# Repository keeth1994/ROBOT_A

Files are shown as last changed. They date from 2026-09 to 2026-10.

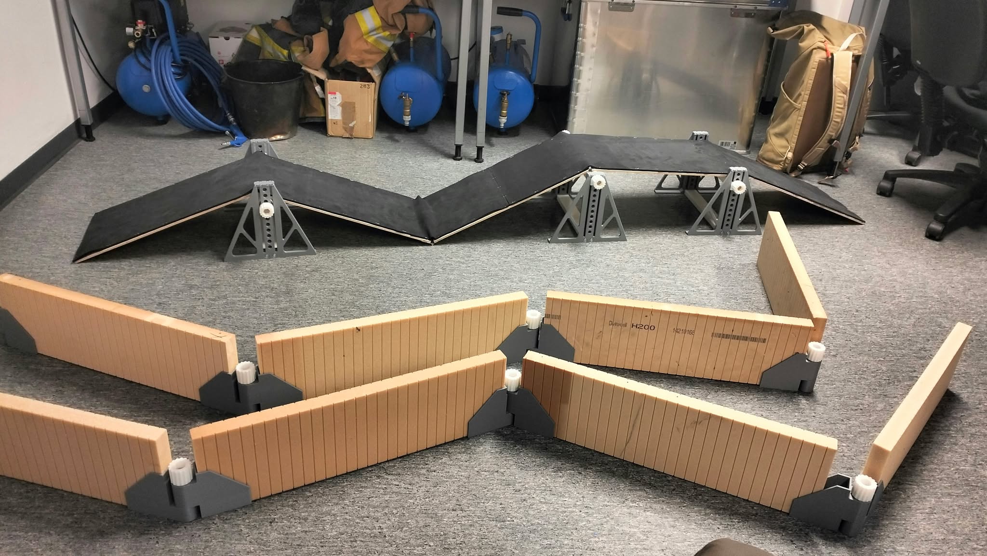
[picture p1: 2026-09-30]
reference/obstacle_course.jpg

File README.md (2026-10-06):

# Robot B9-1

Current Fusion assembly and CAD-derived MuJoCo simulation, using eight original Parallax servos and a physics-driven walking controller.

## Run

From this folder in PowerShell:

```powershell
.\.venv\Scripts\python.exe robot.py walk
.\.venv\Scripts\python.exe robot.py walk --ramp --seconds 100
.\.venv\Scripts\python.exe robot.py walk --test --seconds 15
.\.venv\Scripts\python.exe robot.py check all
```

`start.ps1` and Ctrl+Shift+B in VS Code start the course. Run `robot.py --help` for available commands. No RL training pipeline or trained policy is included.

## Current files

- [Fusion assembly](cad/B9_1/Robot_B9_1.f3d)
- [STEP assembly](cad/B9_1/Robot_B9_1.step)
- [CAD workflow](cad/README.md)
- [Simulation assumptions and results](docs/DESIGN_B91_SIM.md)
- [Machine-readable current design](cad/current_design.json)

| Folder | Contents |
|---|---|
| `robot_b91/` | Model builder, walking controller, geometry and terrain helpers |
| `cad/` | Current assembly, source yaw and Fusion exporter |
| `reference/` | Current CAD export, mass, kinematics, gait and terrain settings |
| `models/` | MuJoCo models and visual meshes |
| `tests/` | Model and entry-point checks |
| `results/` | Current standing, walking and course reports plus preview |

## Setup and rebuild

Use Python 3.12 and install `requirements.txt` into `.venv`. The lock file records pinned dependencies.

After CAD edits, export the saved assembly using `cad/ExportB91` inside Fusion, then run `robot.py build`. This regenerates the simulation from the CAD export. Edit `reference/b91_course_settings.json` to change terrain, then rebuild.

The provisional mass is 1.21 kg. The initial flat test moved 0.505 m in 15 seconds without falling. The 100-second course test drifted and fell; successful course traversal is not established. Physical mass, friction, tolerances and strength still need verification.

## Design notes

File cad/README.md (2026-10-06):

# B9-1 CAD

Open [Robot_B9_1.f3d](B9_1/Robot_B9_1.f3d) in Fusion, or use the [STEP assembly](B9_1/Robot_B9_1.step). The saved assembly is the starting point for edits.

`B9_1/User_yaw_backup.f3d` preserves the source of the current edited fork. Component names inside the assembly retain their original identifiers for traceability.

For simulation export, register `ExportB91` in Fusion Scripts and Add-Ins. It reads the saved archive and writes `reference/b91_cad_meshes.json.gz`. Then run `robot.py build` to regenerate MuJoCo assets. The exporter does not capture unsaved active-tab changes.

See [mechanical notes](B9_1/README.md) and [simulation notes](../docs/DESIGN_B91_SIM.md).

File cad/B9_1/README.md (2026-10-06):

# B9-1 assembly

`Robot_B9_1.f3d` and `Robot_B9_1.step` contain the full assembly. `assembly.png` shows the model. The current edited fork source is retained in `User_yaw_backup.f3d`.

The chassis underside is extended 4 mm to the bearing-housing base plane, retaining openings and bearing seats. Added CAD volume is approximately 48.9 cm3.

`check_report.json` records 784 neutral and sampled pitch clearance checks with no intersections above 0.1 mm3 in the checked pairs. Pitch was sampled from -45 to +45 degrees. Full yaw clearance, physical fit, access and strength remain unverified.

The assembly is transferred to MuJoCo. See [simulation notes](../../docs/DESIGN_B91_SIM.md).

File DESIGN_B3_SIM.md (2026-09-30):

# B3 simulation: narrow feet and supplied sensors

## Model

Native Fusion and STEP exports, CAD-derived visual meshes, approximate inertias and contact shapes are rebuilt from the same B3 geometry. Runner length is 42 mm, flat sole 8 mm, inward tread radius 12 mm, outward tread radius 22 mm, PLA thickness 3 mm and radial section 5 mm. Pitch axle is 60 mm above the neutral sole. Inward reach is deliberately shorter (18 mm versus 24 mm outward).

Estimated total mass: 1.1094 kg. Solid PLA: 284.2 g. Sensor mass additions and the retained electronics/fastener allowances are itemized in `reference/robot_b3_manifest.json`. These are not measured or sliced masses.

Original Parallax 900-00005 servos remain: pitch stall limit 0.26834 Nm, yaw output 0.15206 Nm after 1.5 speed-increasing gears and assumed 85% efficiency. Torque decreases with motoring speed; no thermal, battery-sag or backlash model. Pitch and yaw are limited to +/-45 degrees. Full requested 270-degree yaw is not clearance-certified.

## Course and controller

The photo-inspired ramp has a 300 mm width and five 600 mm horizontal sections. Its provisional height profile is 0 -> 160 -> 0 -> 200 -> 200 -> 0 mm: first climb, first descent into a valley, second climb, raised flat platform, final descent. Thin 6 mm rigid panels have black surfaces, exposed wood-coloured edges and simplified supports. The first slopes are about +/-14.9 degrees and the second climb/descent +/-18.4 degrees. The checkerboard floor remains for visual tracking. Dimensions are assumptions pending measurements; flex and grip are not calibrated.

An independently positioned open zigzag corridor has a provisional 400 mm clear width, 180 mm wall height and 12 mm wall thickness. The settings file exposes both obstacles' positions, rotations and dimensions. There is no ceiling because the photograph shows open walls. The existing controller is unchanged and cannot be assumed to navigate from the ramp into this corridor.

The programmed gait acts through torque/speed-limited motors, without teleportation, base forces or terrain-specific choreography. Ideal simulated heading and lateral feedback remain. After reducing the feet, yaw sweep direction was changed to +0.45 rad; no other gait gains were changed. An earlier unchanged-gait comparison is retained separately and is not the current run.

## Previous-geometry tests (not rerun)

The programmed-gait tests below have not been rerun for the short-sole/rounded-toe revision; new RL experiments on that geometry are documented in `RL_B3.md` and `RL_CURRICULUM.md`. On the preceding foot geometry, the 100 s run advanced 0.499 m, contacted first_climb, floor, and did not complete the ramp. Detected fall: False; warnings: 0; maximum tilt 16.06 degrees. Those previous-geometry results remain in `results/b3_course_test.json` and the replay. The pass criterion requires contact with all five ramp surfaces, clearance of the ramp exit, no fall, no non-foot contact and no ramp-width violation. It assesses the ramp only, not successful corridor navigation. Geometry and sensor validation do not prove traversal capability.

## Sensors

Three Sharp GP2Y0A41SK0F rays provide left, right and downward-forward range observations. Outside 4-30 cm is unknown. MC6470 accelerometer and magnetometer channels are present, with no invented gyro. The TimerCamera-X is represented by a forward RGB camera. `b3_sensors.py` logs observations and captures a camera view. `test_b3_sensors.py` checks wall distances, ground-ray orientation, invalid ranges and channel presence. These tests passed on the previous foot geometry; analogue noise, surface reflectivity, magnetic interference and perception software remain unmodelled. The gait does not yet use these readings. See `SENSORS_B3.md`.

## CAD checks

The audit has 59 recorded overlap cases; inspect `cad/B3_clearance_audit.json` for scope and locations. Own pitch is sampled at 5-degree intervals, FL neutral-pitch yaw at 15 degrees, sensor-vs-leg poses at yaw/pitch -45/0/+45 for all four legs, and stationary sensor packaging is checked. Combined continuous poses, neighbouring moving legs, wiring and strength are not certified. Sensor brackets and other small mounting details contribute mass but are not fully represented by MuJoCo contact geometry.

## Files

`cad/` holds native exports and previews. `models/` holds flat and course XML plus visual meshes. `reference/` holds geometry, sensor and gait configuration. `results/` holds previous-geometry metrics, replay, sensor log and camera view.

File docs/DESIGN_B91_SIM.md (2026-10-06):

# B9-1 MuJoCo transfer

`robot.py walk` and `robot.py build` now use B9-1. The default VS Code course task and `start.ps1` also use B9-1. Use `walk --test` for a saved report. No trained policy or RL training pipeline is included.

```powershell
.\.venv\Scripts\python.exe robot.py walk
.\.venv\Scripts\python.exe robot.py walk --ramp --seconds 100
.\.venv\Scripts\python.exe robot.py walk --test --seconds 15
.\.venv\Scripts\python.exe robot.py check b91
```

## Source and rebuild

Saved source: `cad/B9_1/Robot_B9_1.f3d`. The Fusion exporter `cad/export_b91_sim.py` loads this archive and exports 97 bodies in assembly coordinates to `reference/b91_cad_meshes.json.gz`, including source SHA-256. To run the exporter, register `cad/ExportB91` in Fusion Scripts and Add-Ins. It does not edit the CAD source. Save any new design edits into the source archive before exporting.

`robot.py build` verifies the archive hash, regenerates `models/robot_b91.xml`, `models/robot_b91_course.xml`, their meshes and the mass manifest. Course settings are in `reference/b91_course_settings.json`. B9-1 course metadata is saved separately.

## Mechanical model

- Neutral size: approximately 272 x 272 x 132 mm.
- Yaw axes at (+/-52, +/-52) mm; pitch axes at local (55, 0, 35) mm.
- Pitch motors and rockers move together; the original pitch crosses remain on the yaw forks.
- Eight torque-controlled actuators. Original servo stall limit 0.26834 Nm; yaw output 0.15206 Nm with assumed 1.5 speed ratio and 85% gear efficiency. Speed reduces available motoring torque using the inherited servo model.
- Pitch and yaw are limited to +/-45 degrees pending broader collision validation. Driver gears follow a joint equality constraint.
- CAD visuals, plus 639 segmented convex collision hulls. Collision surfaces use 0.5 mm vertex clustering; small holes, fasteners and bearing internals are omitted. Concave openings are approximated, not exact contact geometry.
- Provisional total mass 1.20999 kg. `reference/b91_mass.json` defines component allowances and material densities. PLA uses full solid CAD volume; actual manufactured mass can differ. Inertias use per-part bounding boxes and CAD centres of mass.
- Three ideal IR rays, a camera and acceleration sensor at CAD-derived package positions. These are not calibrated electrical sensor models; exact IMU capabilities remain to be confirmed.
- Rigid terrain, assumed friction 0.8, no backlash, thermal limits or flexible parts. No imposed base movement or forced course path.

## Initial checks and results

`tests/test_b91.py` verifies source provenance, body count, mass, pitch-axis positions, moving-link assignments, stable standing, foot-only floor contacts, joint motion and torque limits. Both flat and course XML load successfully.

The programmed gait moved 0.505 m forward with 0.0155 m lateral drift in a 15 s flat test (including 2 s settling), without falling or physics warnings. See `results/b91_walk.json`.

In a 100 s course test it moved 0.873 m forward, drifted 0.209 m sideways and fell (maximum tilt 54.9 degrees). There were no physics warnings. See `results/b91_ramp.json`. This is a failed traversal, not a successful demonstration of the obstacle course.

No learned policy is included or validated for this model.

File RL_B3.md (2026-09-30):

# B3 reinforcement learning on flat ground

This is a separate PPO controller that learns eight absolute yaw/pitch targets. It does not call the programmed gait, prescribe a foot trajectory, teleport the body, or apply external forces. MuJoCo contacts and the original Parallax torque/speed limits produce movement. The existing course controller remains available separately.

## Run

From the repository terminal:

```powershell
.\.venv\Scripts\python.exe -m pip install -r requirements-rl.txt
.\.venv\Scripts\python.exe train_b3_rl.py --strict --steps 262144 --envs 8 --minutes 10
.\.venv\Scripts\python.exe watch_b3_rl.py
```

VS Code: **Terminal > Run Task > B3 RL - train straight line** or **B3 RL - watch learned policy**. The watch command repeats a deterministic 10-second evaluation. The default build task still opens the programmed obstacle-course gait, not RL.

Continue from a saved policy into a new output directory:

```powershell
.\.venv\Scripts\python.exe train_b3_rl.py --resume results/rl_flat/latest.zip --out results/rl_flat_continued --steps 1000000 --minutes 20
.\.venv\Scripts\python.exe watch_b3_rl.py --model results/rl_flat_continued/best.zip
```

`--steps` is the number of additional policy transitions across all environments; each transition represents 20 ms, using ten 2 ms physics steps. The time cap applies during learning; startup and evaluation add time. Checkpoints are local. A policy must be retrained/revalidated when the robot geometry, control mapping or observation definition changes.

## Task and measurement

Each episode starts on the checkerboard floor, settles for 0.3 s, then lasts up to 10 s. Initial joint angles have small seeded perturbations. PPO receives ideal simulator joint angles/velocities, base velocity, angular velocity, orientation, lateral position, height, and its previous action. These are privileged simulator observations; the supplied servo/sensor package does not directly provide all of them. This experiment is not yet a deployable hardware controller.

Reward favours forward velocity and penalizes lateral motion/displacement, heading error, tilt, power, command changes and non-foot floor contact. Episodes terminate for falls, excessive drift/heading, or numerical warnings. Success is at least 0.30 m forward in 10 s, maximum lateral error 0.04 m, maximum heading error 15 degrees, and no fall, non-foot contact or warnings. Distance alone is not success.

The policy outputs joint positions within +/-45 degrees; a PD servo controller uses the same torque-speed envelope as the existing gait. Pitch stall limit is approximately 0.2683 Nm and geared yaw approximately 0.1521 Nm. No motor upgrade. Mass, friction, actuator and inertia approximations are inherited from the current model. No curriculum, gait imitation, phase clock, obstacle navigation or domain randomization is included in this first experiment.

PPO implementation: [Stable Baselines3](https://stable-baselines3.readthedocs.io/en/master/modules/ppo.html), with a [custom Gymnasium environment](https://stable-baselines3.readthedocs.io/en/master/guide/custom_env.html).

## Outputs and checks

`results/rl_flat/` contains standing and untrained baselines, `progress.csv`, periodic `learning_curve.json`, `best.zip`, `latest.zip`, and final `summary.json` with model hash and revision. Best checkpoint means highest evaluation reward, not necessarily successful walking. Check actual success and distance in the summary. Training environments use different seeds; checkpoint evaluation uses seeds 1000-1001 and final reporting 1000-1004. One training seed is a preliminary experiment, not proof of robust learning.

```powershell
.\.venv\Scripts\python.exe test_b3_rl.py
.\.venv\Scripts\python.exe watch_b3_rl.py --record results/rl_flat/replay.mp4
```

The tests check the Gym API, reproducible resets, full-CAD/headless trajectory parity, motor torque caps and absence of external forces. Training removes only non-colliding CAD visual meshes; contact geometry, body masses and inertia remain intact.

## Initial experiment results

See [measured training and evaluation results](results/RL_REPORT.md). The default viewer uses the selected policy in `reference/b3_rl_policy.json`. The first experiment learned forward movement quickly, but passes strict straight-line criteria on only 2/10 new seeds.

`--strict` increases the lateral-displacement penalty from 4 to 15 and the heading penalty from 0.3 to 1.5. Reward weights are recorded in the run summary. Use `evaluate_b3_rl.py --model PATH --episodes 10 --out REPORT.json` for new-seed evaluation; add `--fine` for 1 ms physics.

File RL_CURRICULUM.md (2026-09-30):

# B3 straight-line and gentle-ramp curriculum

These lessons retain the current robot, original motor torque/speed limits, 20 ms policy interval and learned joint-target action space. They use ideal simulator feedback, with no programmed gait, imposed body motion or physical guide rails. No new terrain sensors are invented: the policy reacts using the same body/joint observations as the flat-ground experiment.

Stage 1 is a 10 s flat-ground trial: at least 0.5 m forward, maximum lateral displacement 3 cm, maximum heading error 10 degrees, no fall, non-foot ground contact or warnings. Speed reward saturates at 0.08 m/s, and alignment reduces the reward for faster diagonal motion. Drifting beyond 10 cm or turning beyond 40 degrees ends training episodes.

Stage 2 uses separate 3-degree and 5-degree lessons: 30 cm flat approach, 40 cm ascent, 20 cm level top, 40 cm descent. Ramp width is 30 cm. Heights are approximately 21 mm and 35 mm. The panels are rigid, with the same assumed friction as the existing simulation. Completion requires contact with ascent, top and descent and the body clearing x=1.45 m within 25 s. The same 3 cm/10 degree limits apply. Stepping off the side is a failure. A standing policy cannot pass.

Checkpoint selection prioritizes the success rate on three development seeds, then physical completion, then reward. Twenty separate seeds (4000-4019) assess each selected checkpoint. A stage gate requires 90% success. These seeds vary initial joint angles slightly; they are not a broad hardware/domain-randomization study. Results on gently sloping ramps do not establish capability on the full course.

## Commands

```powershell
.\.venv\Scripts\python.exe train_b3_curriculum.py --resume results/rl_flat_straight/best.zip --out results/curriculum_flat --steps 393216
.\.venv\Scripts\python.exe train_b3_curriculum.py --slope 3 --resume results/curriculum_flat/best.zip --out results/curriculum_3deg --steps 262144
.\.venv\Scripts\python.exe train_b3_curriculum.py --slope 5 --resume results/curriculum_3deg/best.zip --out results/curriculum_5deg --steps 262144
.\.venv\Scripts\python.exe watch_b3_rl.py --curriculum --slope 3 --model results/curriculum_3deg/best.zip
.\.venv\Scripts\python.exe watch_b3_rl.py --curriculum --slope 5 --model results/curriculum_5deg/best.zip
```

Each run saves its initial evaluation, learning curve, best and latest checkpoints, and a summary with validation metrics and model/environment hashes. Continuing from a checkpoint adds `--steps` transitions; it does not reset the learned policy. `--minutes` caps the training portion, with evaluation time additional. Keep each experiment in a distinct output folder.

Checks: `test_b3_curriculum.py` verifies physical ramp heights/width, headless/full-CAD parity, contact accounting and rejection of a stationary policy. `test_b3_rl.py` checks original environment compatibility and actuator limits.

## Observation scaling and continued practice

The refined runs scale small velocity, tilt and lateral-position inputs before the network. The first layer is adjusted when converting an old policy, preserving its initial action mapping. Checkpoint metadata records this convention, and the viewer detects it automatically. `--normalized` enables conversion; later resumes inherit it. `--exploration-std 0.2` or `0.15` reduces exploration during fine-tuning.

Slope runs use two flat and six sloped training environments. After training, the selected ramp policy is also checked on twenty flat-ground seeds (5000-5019) for regression. Existing experiment directories cannot be overwritten by the curriculum trainer.

VS Code offers separate viewing tasks for the refined flat policy and each gentle ramp. These do not replace the original full obstacle-course task.

## Current measured results

See [final fresh-seed report](results/CURRICULUM_REPORT.md). Flat: 20/20 clean passes. 3 degrees: 17/20 physical completions, 6/20 clean passes. 5 degrees: 3/20 physical completions, 1/20 clean pass. These are separate selected checkpoints, not one policy verified for every terrain. Selected files are listed in `reference/b3_curriculum_policies.json`; the default viewer opens the selected flat policy.

The commands above reproduce the original experiment sequence; choose unused output directories when rerunning them. To continue the 5-degree lesson:

```powershell
.\.venv\Scripts\python.exe train_b3_curriculum.py --slope 5 --resume results/curriculum_selected/5deg/policy.zip --out results/curriculum_5deg_next --steps 1000000 --minutes 15
```

For a fresh evaluation, use `--evaluate-only --evaluation-seed 9000` with a new output directory. Viewer `--seed` selects the reset seed.

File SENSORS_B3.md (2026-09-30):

# Supplied project sensors on B3

Selection is based on page 9 (Project components) of `Final project introduction 2026.pdf`. Sensor quantities are a proposed layout; the document does not state available quantities.

| Part | Quantity | Location / purpose |
|---|---:|---|
| Sharp GP2Y0A41SK0F, RS 666-6568 | 3 | One left, one right, one front looking down 30 degrees. Wall clearance and ground profile. |
| MIKROE-4228 / MC6470, RS 249-4068 | 1 | Rigid rear deck cradle. Acceleration and magnetic field. **No gyroscope.** |
| M5Stack TimerCamera-X U082-X, RS 230-5140 | 1 | Forward-facing camera in open deck cradle. RGB observation; no depth output. |

The suggested VL53L5CX, VL53L1X and BMI270 are not in the project list and are not fitted. The listed Ohmite FSR02CE is a 622.3 mm strip, so it is excluded instead of being misrepresented as a small foot pad. No servo position encoders are added.

## Geometry and mass

Sharp packages use the manufacturer's 29.5 x 13 x 13.5 mm envelope and 3.6 g mass. The camera uses 48 x 24 x 15 mm and 14 g. The MC6470 board footprint is 28.6 x 25.4 mm; a 10 mm installed-height envelope and the manufacturer's listed 17 g weight are conservative provisional allowances, to be checked physically. The old 3 g generic IMU reservation is replaced. These are package envelopes, not exact connector/optical-window models.

Open PLA cradles use adhesive pads/cable-tie slots. Body clearance and connector access need physical checks before printing. Sensor cases have dedicated simulation mass and collision boxes. Small cradle collision details remain omitted from MuJoCo, but are included in CAD checks and mass. The 90 g controller/electronics and 80 g miscellaneous allowances remain separate; neither is a finalized bill of materials.

## Simulation interface

`b3_sensors.py` exposes three range readings, 3-axis specific acceleration and magnetic field, plus a `project_camera` RGB view. Run:

```powershell
.\.venv\Scripts\python.exe test_b3_sensors.py
.\.venv\Scripts\python.exe b3_sensors.py --ramp --seconds 3
```

Outputs are `results/b3_sensor_test.json`, `results/b3_sensor_samples.json` and `results/b3_camera_view.png`. Range observations outside 0.04-0.30 m are marked unknown. A missing return is not a proven drop-off. The rays are ideal point samples, not models of Sharp analogue response, beam footprint, dark-rubber reflectance or electrical noise. Magnetometer motor interference is not simulated. Camera FOV uses the published 66.5-degree diagonal angle with an assumed 4:3 image.

The locomotion controller still uses ideal simulated heading/lateral position. Adding sensors does not implement autonomous perception or navigation, and the new sensor data do not secretly replace that feedback. Ground readings change with robot tilt; the listed accelerometer/magnetometer cannot provide gyro rates.

## Wiring notes

Sharp sensors need a regulated 4.5-5.5 V supply, local bypass capacitors and calibrated analogue inputs. Verify ADC voltage protection/dividers for the selected ESP32. The Click board uses 3.3 V I2C. Camera power/communications follow the TimerCamera-X documentation. Measure the installed modules, cable bend space and printed fit before manufacturing.

## Sources

- Project component links: https://no.rs-online.com/web/p/reflective-optical-sensors/6666568 ; https://no.rs-online.com/web/p/sensor-development-tools/2494068 ; https://no.rs-online.com/web/p/development-tool-accessories/2305140
- Sharp datasheet: https://global.sharp/products/device/lineup/data/pdf/datasheet/gp2y0a41sk_e.pdf
- MC6470 board: https://www.mikroe.com/6dof-imu-13-click
- Camera: https://docs.m5stack.com/en/unit/timercam_x
- Ohmite force sensor: https://docs.rs-online.com/8bfb/A700000007054155.pdf

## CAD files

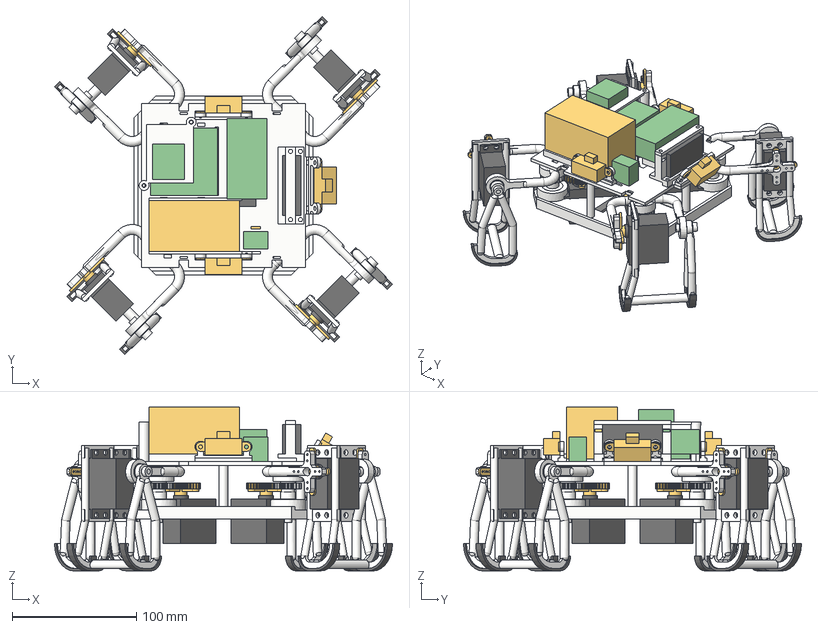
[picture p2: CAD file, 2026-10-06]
cad/B9_1/Robot_B9_1.step
272.3 x 272.3 x 132.0 mm

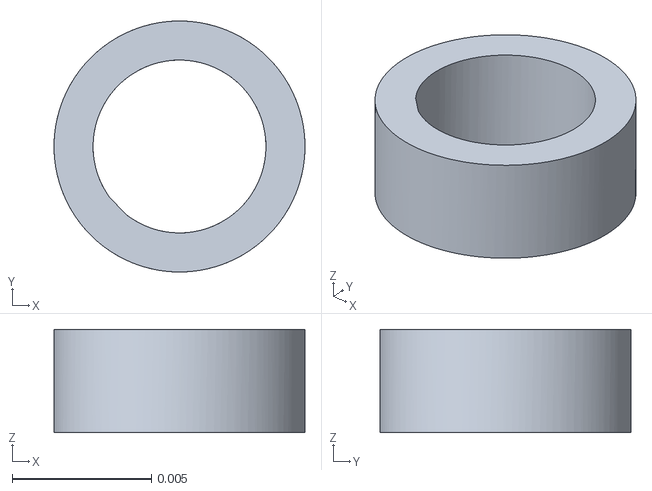
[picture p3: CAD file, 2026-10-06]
models/robot_meshes_b91/cad_72.obj
0.009 x 0.009 x 0.0037

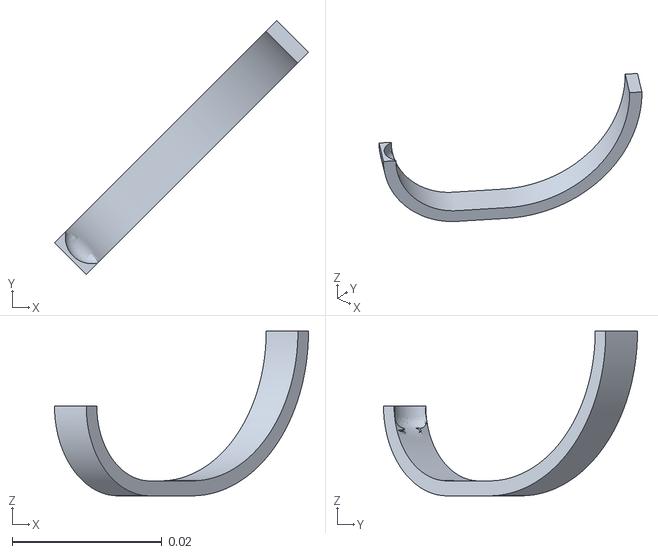
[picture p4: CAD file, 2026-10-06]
models/robot_meshes_b91/cad_9.obj
0.0339 x 0.0339 x 0.022

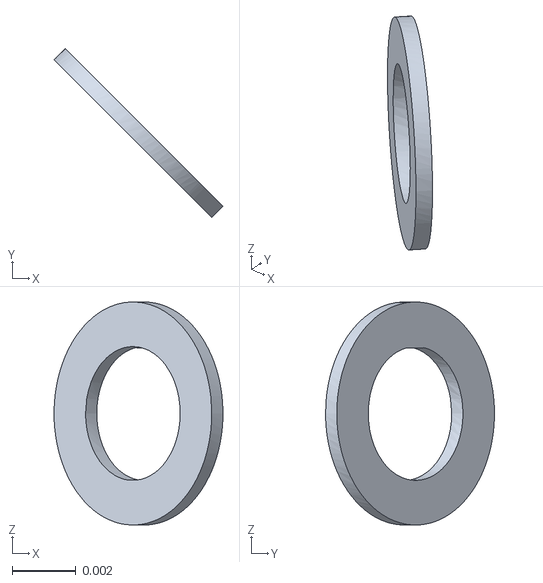
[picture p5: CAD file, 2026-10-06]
models/robot_meshes_b91/cad_70.obj
0.0053 x 0.0053 x 0.007

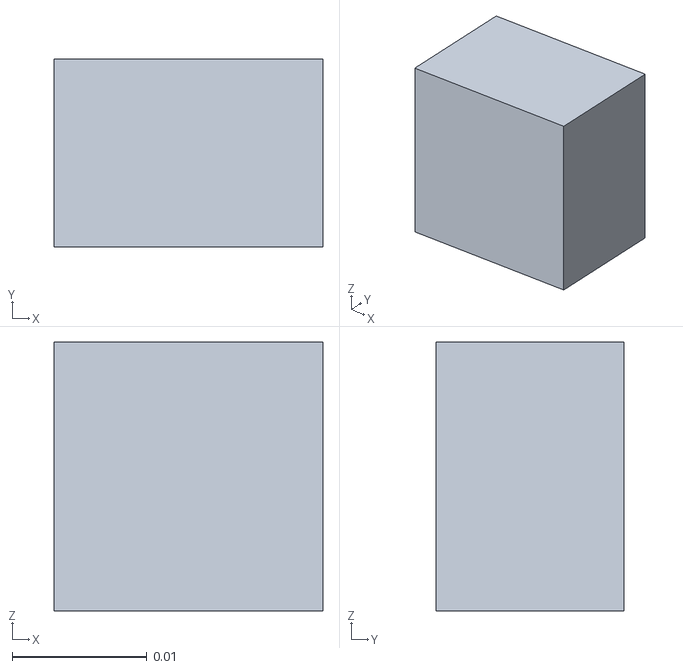
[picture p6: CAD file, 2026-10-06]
models/robot_meshes_b91/cad_96.obj
0.02 x 0.014 x 0.02

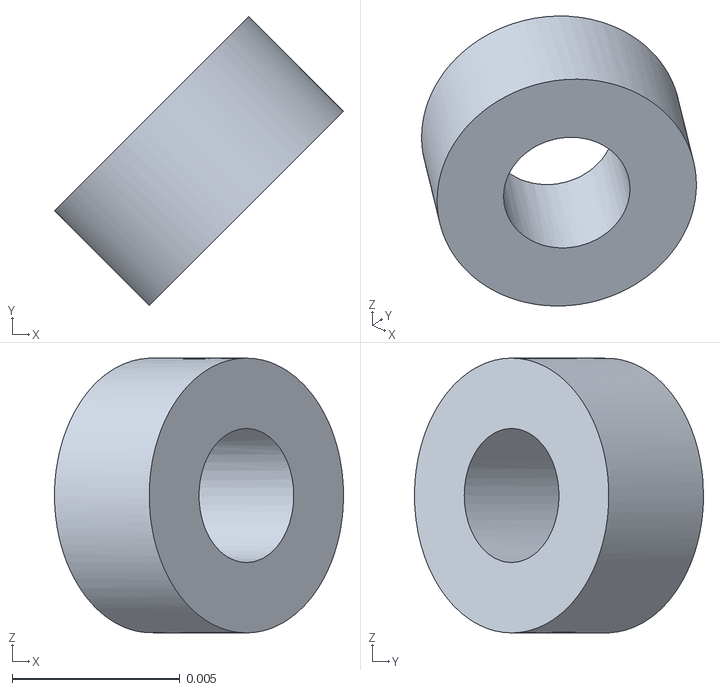
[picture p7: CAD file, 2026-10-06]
models/robot_meshes_b91/cad_53.obj
0.00863 x 0.00863 x 0.0082

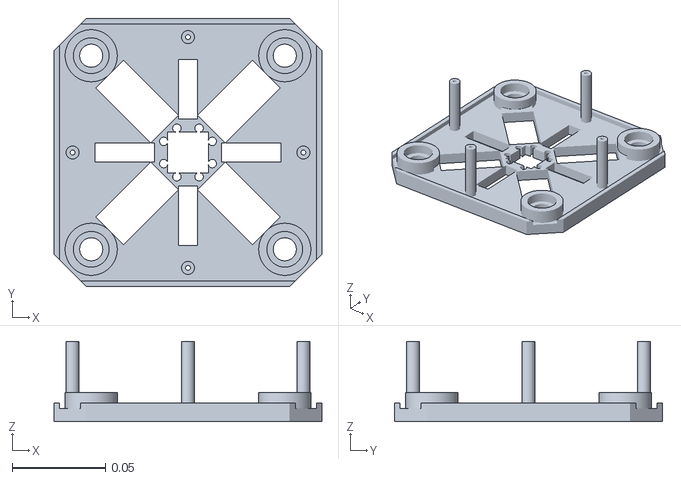
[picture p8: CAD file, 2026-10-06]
models/robot_meshes_b91/cad_0.obj
0.144 x 0.144 x 0.043

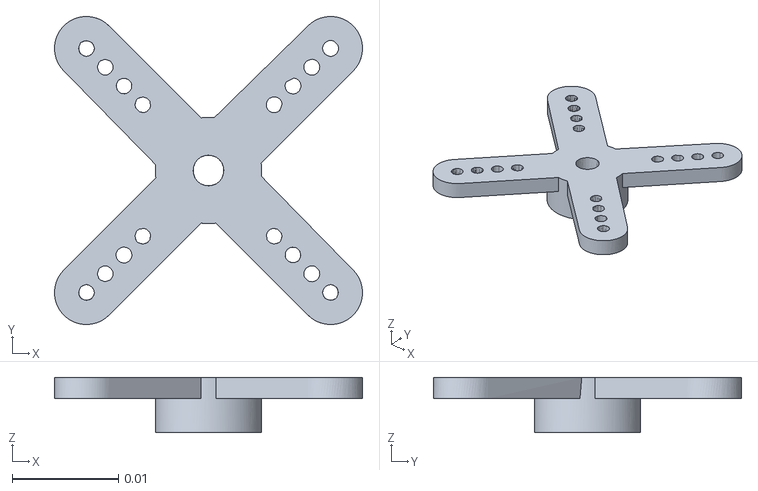
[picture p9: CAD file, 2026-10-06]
models/robot_meshes_b91/cad_66.obj
0.029 x 0.029 x 0.0052

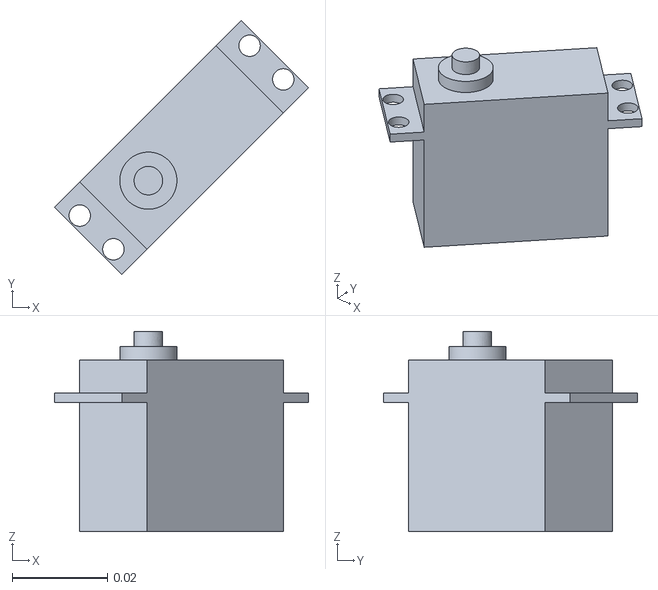
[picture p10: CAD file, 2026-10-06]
models/robot_meshes_b91/cad_26.obj
0.0534 x 0.0534 x 0.0421

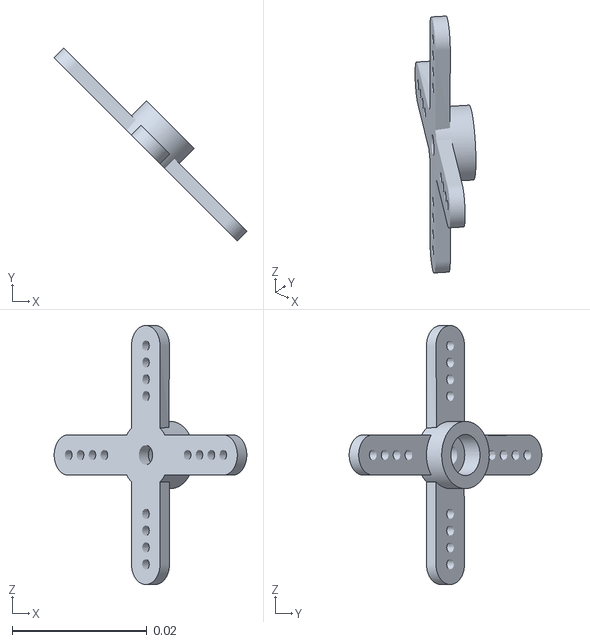
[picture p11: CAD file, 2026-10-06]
models/robot_meshes_b91/cad_22.obj
0.0286 x 0.0286 x 0.0385

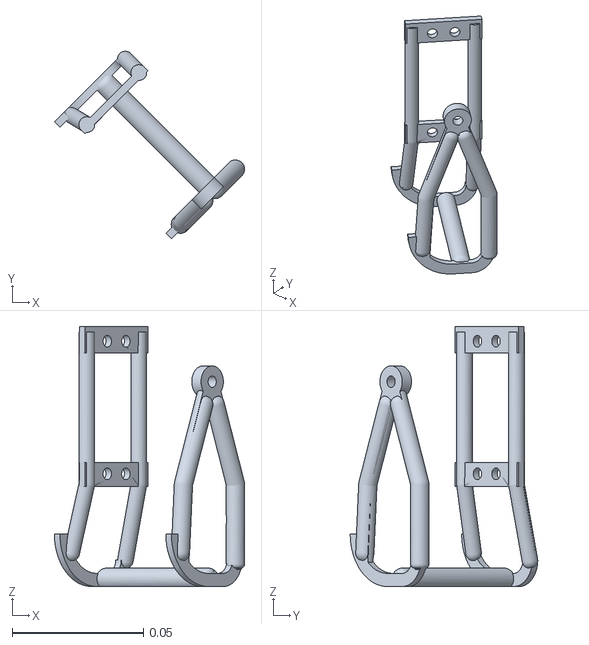
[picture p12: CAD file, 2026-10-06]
models/robot_meshes_b91/cad_31.obj
0.0724 x 0.0714 x 0.099

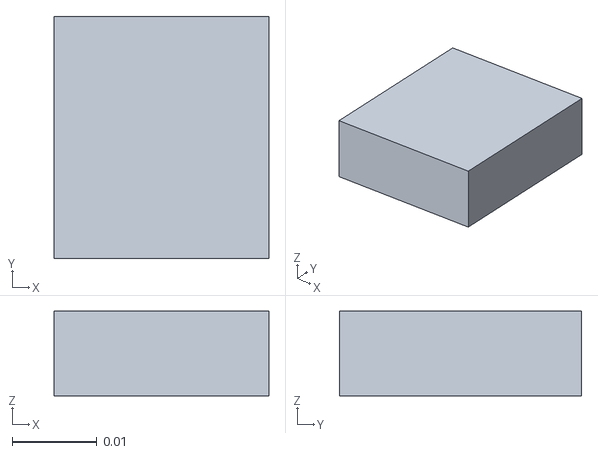
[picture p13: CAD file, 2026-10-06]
models/robot_meshes_b91/cad_95.obj
0.0254 x 0.0286 x 0.01

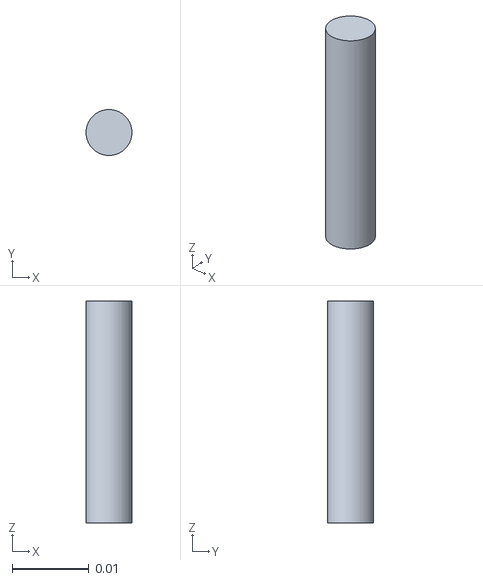
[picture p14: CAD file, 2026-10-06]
models/robot_meshes_b91/cad_73.obj
0.006 x 0.006 x 0.029

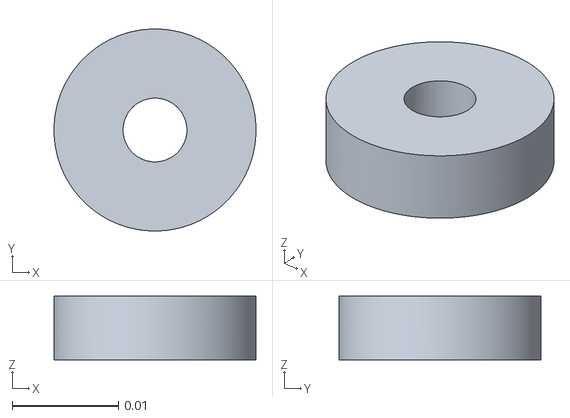
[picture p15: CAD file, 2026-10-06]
models/robot_meshes_b91/cad_68.obj
0.019 x 0.019 x 0.006

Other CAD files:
models/robot_meshes_b91/cad_10.obj
models/robot_meshes_b91/cad_60.obj
models/robot_meshes_b91/cad_79.obj
models/robot_meshes_b91/cad_81.obj
cad/B9_1/Robot_B9_1.f3d
cad/B9_1/User_yaw_backup.f3d
models/robot_meshes_b91/cad_1.obj
models/robot_meshes_b91/cad_11.obj
models/robot_meshes_b91/cad_12.obj
models/robot_meshes_b91/cad_13.obj
models/robot_meshes_b91/cad_14.obj
models/robot_meshes_b91/cad_15.obj
models/robot_meshes_b91/cad_16.obj
models/robot_meshes_b91/cad_17.obj
models/robot_meshes_b91/cad_18.obj
models/robot_meshes_b91/cad_19.obj
models/robot_meshes_b91/cad_2.obj
models/robot_meshes_b91/cad_20.obj
models/robot_meshes_b91/cad_21.obj
models/robot_meshes_b91/cad_23.obj
models/robot_meshes_b91/cad_24.obj
models/robot_meshes_b91/cad_25.obj
models/robot_meshes_b91/cad_27.obj
models/robot_meshes_b91/cad_28.obj
models/robot_meshes_b91/cad_29.obj
models/robot_meshes_b91/cad_3.obj
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

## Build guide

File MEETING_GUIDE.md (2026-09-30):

# Group meeting demos

Double-click MEETING_DEMOS.cmd in the repository and select 1, 2, or 3.
Close the MuJoCo window to exit. Live episodes repeat automatically.
Alternatively, VS Code: Terminal > Run Task > Meeting demo - normal / rl-flat / rl-ramp.
Option 4 opens the labelled video backups in results/meeting. Videos play at real time (1x).

## Suggested presentation order

1. Normal walk: a manually programmed joint gait using simulated motor forces.
2. RL flat: PPO chooses eight joint targets from observations; no programmed gait or forced body trajectory.
3. RL ramp: your successful my_3deg_run_02/best.zip climbs, crosses the top, and descends a 3 degree lesson ramp.

All demos retain the original servo torque/speed limits and current geometry.
The flat and ramp RL demos use separate checkpoints. They are not one policy validated on every course.
The camera follows on flat ground; checkerboard motion and the distance counter show progress.

## Recorded examples (seed 4000)

- Normal: 0.194 m in 12 seconds, including its initial 2-second standing period.
- RL flat: 1.356 m in 10 seconds, clean success.
- RL ramp: 1.450 m in 9.76 seconds, clean success across all three ramp surfaces.

These are individual demonstrations, not a controlled speed benchmark: the normal gait has a startup delay and the RL environments settle before timing.
Your saved ramp evaluation reports 19/20 successful trials (95%). This does not establish performance on the much steeper photographed obstacle course.
Ideal simulation state feedback is used. Real sensor estimation, friction, printed stiffness and hardware behavior still need validation.

## Terminal commands (from the repository)

```powershell
.\.venv\Scripts\python.exe meeting_demo.py normal
.\.venv\Scripts\python.exe meeting_demo.py rl-flat
.\.venv\Scripts\python.exe meeting_demo.py rl-ramp
```

Add --record to regenerate the corresponding labelled MP4 and JSON report in results/meeting.
Add --seed 4010 to inspect another RL initial condition. No training is launched by these demos.

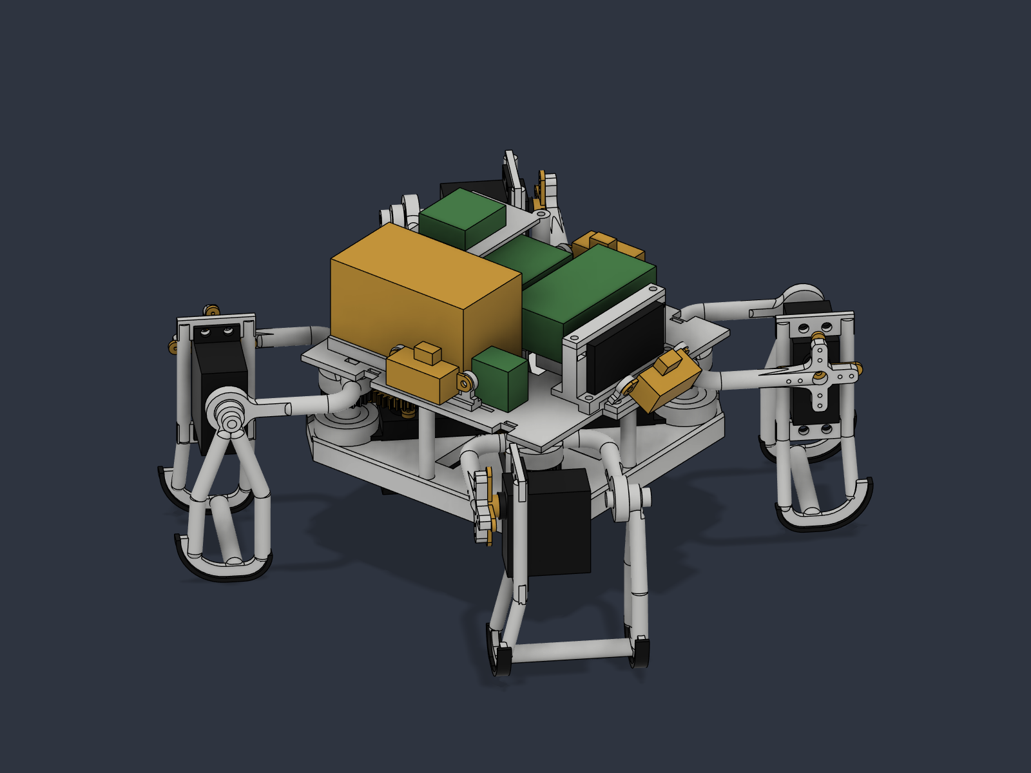
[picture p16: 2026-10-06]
cad/B9_1/assembly.png

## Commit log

2026-09-29 new robot and cleanup
    [B3_Y_Fork_Detail.f3d, B3_Y_Fork_Detail.step, FL_distal_pitch_Black.obj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]
2026-10-06 versjon B9-1
    [B3_Y_Fork_Detail.f3d, B3_Y_Fork_Detail.step, B4_Reinforced_Leg_Detail.f3d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]
2026-10-08 Include the 4 new servos and update simulation properties
    Configure servos at 5V (because of the controller output)
    Use HS-475HB/MG995 for yaw and Parallax for pitch
    Update torque, speed, mass and 50 Hz command handling
    Add IMU gyro and IR range validation
2026-10-11 Add ramp traversal gait and ESP32 firmware prototype
2026-10-22 Add ESP32 and TimerCamera ino scripts
    ESP32 as a hotspot
2026-10-22 Add local PC dashboard and connect ESP32s to PC hotspot
2026-10-22 Add IMU and camera
2026-10-23 Add IMU and camera ramp navigation
2026-10-28 Update current CAD model to B9-8
2026-10-29 Add servo calibration scripts
2026-10-29 Add servo calibration UI
2026-10-29 Expanded pitch range
